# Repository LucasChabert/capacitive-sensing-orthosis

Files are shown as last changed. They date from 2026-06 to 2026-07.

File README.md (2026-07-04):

<div align="center">

# 🦾 Capteurs capacitifs imprimés en 3D pour orthèses d'exosquelette

### Capteurs de pression et de position par mesure capacitive en impression 3D multi-matériaux







*Stage de recherche L1 MPCI · Inria / IRISA, équipe Rainbow (Rennes) · Juin–Juillet 2026*

**🇫🇷 Français** · [🇬🇧 English](README.en.md)

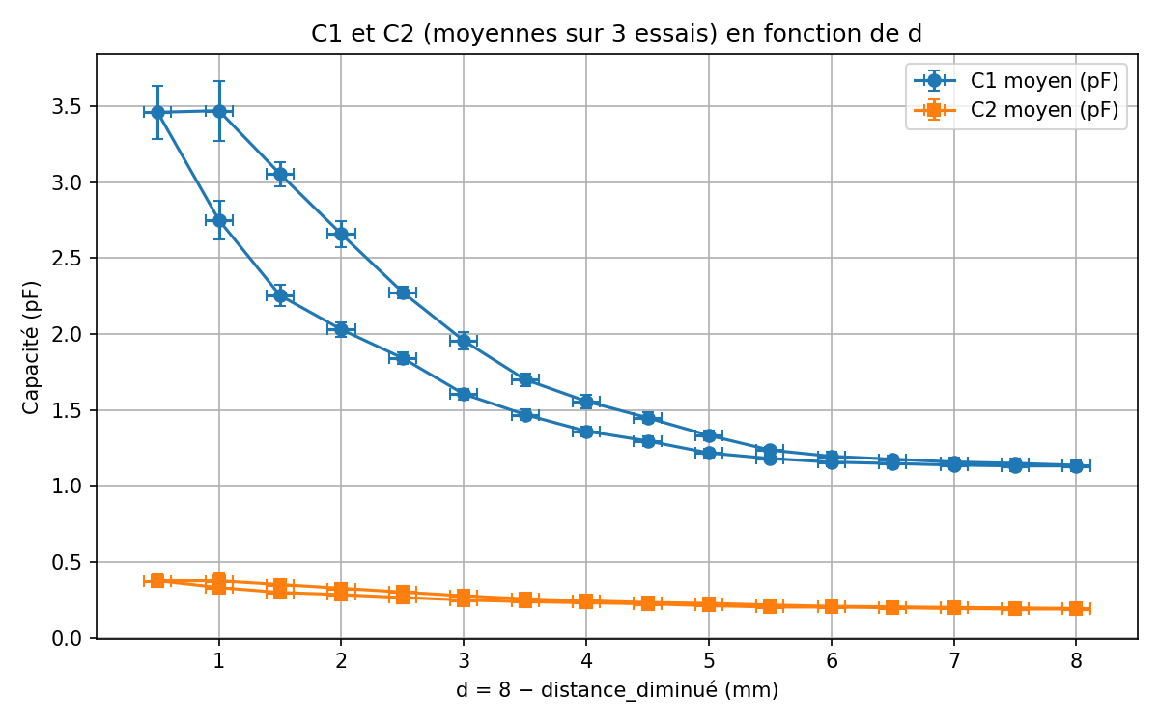
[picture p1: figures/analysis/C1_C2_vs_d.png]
Hystérésis des capacités C1 et C2 en fonction de l'écartement d


*Le résultat central du stage : pour un même écartement d, la capacité mesurée diffère
selon que la mousse diélectrique est en compression ou en relâchement — une hystérésis
interprétée comme une permittivité dépendante de l'histoire de la déformation.*

</div>

---

## 🎯 Contexte

Les exosquelettes d'assistance du membre supérieur estiment l'intention de mouvement
de l'utilisateur via des **capteurs de force 3 axes** — précis, mais lourds, encombrants
et coûteux. Ce stage explore une alternative : **intégrer des capteurs capacitifs
directement dans les orthèses** (les interfaces physiques humain–machine), fabriqués
en une seule étape par **impression 3D multi-matériaux** — matériau conducteur
(EEL 90A) pour les électrodes, élastomère souple (Filaflex 70A) pour les zones
déformables, TPU 95A pour la structure.

> 🔬 **Question** — Peut-on mesurer une pression (et sa position) avec des cellules
> capacitives imprimées, de façon suffisamment fiable pour instrumenter une orthèse ?

Le travail s'appuie sur les travaux de l'équipe Rainbow sur l'exosquelette du membre
supérieur et sur les capteurs capacitifs imprimés [1–4].

## ⚙️ Principe de mesure

Un condensateur plan suit `C = εS/d`. Pour s'affranchir de `ε` et `S`, mal connus,
on mesure **deux cellules en différentiel** séparées d'un décalage connu `Δd` :

```
d = Δd / (C1/C2 − 1)
```

Quand les électrodes sont superposées (V3), les permittivités diffèrent et le modèle
est étendu avec `α = ε1/ε2`, estimé par une calibration au repos. La chaîne de mesure :
puce **FDC1004** (mesure capacitive, blindage actif SHLD) → **M5Stack Core (ESP32)**
programmé en C++ via PlatformIO → visualisation Teleplot (résolution ±0,001 pF).

## 🔁 Démarche itérative

| Version | Conception | Enseignement |
|---|---|---|
| **V1** — cellules côte à côte | preuve de concept, mousse gyroïde | trop sensible à la position du doigt |
| **V2** — blindage | shield masse + blindage actif SHLD | perturbations environnementales fortement réduites |
| **V3** — électrodes superposées | même déformation pour les 2 cellules | nécessite le modèle à deux permittivités (α) |
| **V4** — capteur de position | électrodes triangulaires complémentaires | position via `x = L·C1/(C1+C2)`, ratio borné → calibration affine |
| **V5** — pilier / support soluble | variantes mécaniques | ouverture |

## 📊 Résultats clés

- **Hystérésis du diélectrique** mise en évidence et interprétée : la permittivité
  effective de la mousse est une **variable d'état** `ε(H)` dépendant de l'histoire de
  compression — le modèle géométrique bijectif `C = εS/d` ne suffit plus.
- **Identification de modèle** par moindres carrés (`scipy.optimize.least_squares`) :
  la forme `C(d) = A/(d+B) + C_b` ajuste les mesures, chaque paramètre ayant une
  interprétation physique (offset de contact, capacité de bord, εS).
- La grandeur `1/C2 − 1/C1`, prédite constante, est en réalité **linéaire en d
  (R² ≈ 0,95)** et moins hystérétique : c'est la compression du support « rigide » qui
  porte le signal → piste d'un **capteur à diélectrique solide**.
- **Capteur à cellule unique** : une seule courbe `C(d)` ajuste charge et décharge
  (R² = 0,91), l'hystérésis restant sous l'incertitude de mesure.
- **Capteur de position** : ratio expérimental borné dans [0,4 ; 0,6] au lieu de [0, 1],
  expliqué par un modèle à capacités parasites, corrigé par calibration affine.

## 📁 Structure du dépôt

```
├── docs/report.pdf        ← rapport de stage complet
├── firmware/              ← code embarqué ESP32 (PlatformIO)
│   ├── src/               ← main.cpp + driver FDC1004 (ProtoCentral, MIT)
│   └── variants/          ← versions pression simple / position / calibration affine
├── analysis/              ← scripts Python : fits moindres carrés, hystérésis,
│                            reconstruction de d, incertitudes
├── data/                  ← mesures du banc de test (CSV/XLSX) + acquisitions Teleplot
├── cad/                   ← modèles Fusion 360 + STL/3MF des 5 versions de prototypes
└── figures/               ← rendus CAO et figures de résultats (régénérables)
```

## 🚀 Prise en main

**Analyse (Python)** :
```bash
pip install -r requirements.txt
cd analysis
python ajustement_C1_modeles_bord_sans_offset_en_d.py   # fits C1 avec/sans effets de bord
python mesure_capacites_inverse_et_rapport.py           # linéarité de 1/C2 − 1/C1
python Retrouver_d.py                                   # reconstruction de d
```
Les figures sont écrites dans `figures/analysis/`.

**Firmware (ESP32 / M5Stack)** : ouvrir `firmware/` avec [PlatformIO](https://platformio.org/)
(`pio run -t upload`). Voir `firmware/variants/README.md` pour les autres versions.

## 👤 Auteur

**Lucas Chabert** — L1 MPCI, Aix-Marseille Université.
Stage encadré par **Maxime Manzano**, Inria/IRISA, équipe Rainbow (Rennes).

## 📚 Références

1. Aguilar-Segovia, J. E. (2026). *Additive Manufacturing of Deformable Sensing Devices for Human–Machine Interaction…* Thèse, INSA Rennes. [HAL](https://theses.hal.science/tel-05587063v1)
2. Aguilar-Segovia et al. (2024). *Multi-material torque sensor embedding one-shot 3D-printed deformable capacitive structures.* IEEE Sensors Letters 8(9). [HAL](https://hal.science/hal-04699911v1)
3. Manzano et al. (2025). *Enhancing the Usability of Upper-Limb Assistive Robots with a Variable Admittance Controller.* IFRATH 2025. [HAL](https://hal.science/hal-05356901)
4. Manzano et al. (2024). *Force-Triggered Control Design for User Intent-Driven Assistive Upper-Limb Robots.* IEEE/RSJ IROS 2024. [HAL](https://hal.science/hal-04774539v1)

---

<div align="center">

**📄 [Rapport complet (PDF)](docs/report.pdf)** 

</div>

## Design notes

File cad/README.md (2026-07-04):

# Modèles CAO (Fusion 360)

Prototypes conçus itérativement — sources `.f3d`, exports `.stl` et projets
slicer `.3mf` (PrusaSlicer, profils multi-matériaux EEL 90A / Filaflex 70A /
TPU 95A). Les `.gcode` sont exclus du dépôt (régénérables depuis les `.3mf`).

| Dossier | Version | Rapport |
|---|---|---|
| `v1_cellules_cote_a_cote/` | V1 — deux cellules côte à côte (preuve de concept) | §3.2 |
| `v2_blindage/` | V2 — introduction du blindage électrostatique | §3.4.1 |
| `v3_superpose_blinde/` | V3 — électrodes superposées + shield | §3.3 |
| `v4_position/` | V4 — capteur de position à électrodes triangulaires | §4 |
| `v5_test_pilier/` | V5 — essai avec pilier / support soluble (PVA) | ouverture |

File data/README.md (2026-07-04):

# Données expérimentales

- `Book1.csv` / `Book1.xlsx` / `Book2.xlsx` — mesures du banc de test (étau) :
  capacités C1, C2 en fonction de l'écartement d, branches charge/décharge.
  Utilisées par les scripts de `analysis/`.
- `teleplot_*.csv` — acquisitions brutes (M5Stack → Teleplot).
- `Data2.csv` — mesures du prototype V1.2 empilé.

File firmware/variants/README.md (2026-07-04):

# Variantes de firmware

Le firmware compilé par PlatformIO est `../src/main.cpp` (capteur de pression,
mesure différentielle C1/C2). Ce dossier archive les autres versions
développées pendant le stage — pour en utiliser une, remplacer le contenu de
`src/main.cpp` :

| Fichier | Rôle |
|---|---|
| `main_simple.cpp` | Lecture brute d'une seule capacité (prise en main FDC1004) |
| `main_v2.cpp` | Variante de la mesure différentielle |
| `main_DL.cpp` | Variante avec distinction charge/décharge |
| `position.cpp` | Capteur de position (électrodes triangulaires, ratio C1/(C1+C2)) |
| `position_affine.cpp` | Capteur de position avec calibration affine x = aR + b |

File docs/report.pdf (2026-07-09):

Stage de recherche — L1 MPCI

# Capteurs de pression et de position

# par mesure capacitive en impression 3D

# multi-matériaux

Application à l’instrumentation d’orthèses pour exosquelette d’assistance du membre supérieur

Inria/IRISA — équipe Rainbow

Lucas Chabert

Encadré par Maxime Manzano

du 01/06/2026 au 01/07/2026, année universitaire 2025–2026

## Table des matières

1 Introduction | 1
2 Principe de fonctionnement | 2
3 Développement d’un capteur de pression | 4
4 Vers une mesure de la position du point de pression | 13
5 Conclusion et ouverture | 15
Remerciements | 15
A Capacité équivalente en série | 16
B Expression de C2 en fonction de d | 16
C Méthode des moindres carrés | 17
D Coefficient de détermination | 17
E Bornes du ratio du capteur de position | 18

Capteurs capacitifs imprimés en 3D | Inria/IRISA — Rainbow

## 1 Introduction

La perte de mobilité du membre supérieur, qu’elle soit d’origine neurologique, musculaire ou traumatique, affecte profondément l’autonomie des personnes concernées dans les gestes de la vie quotidienne. Pour tenter de la restaurer, la recherche en robotique d’assistance s’est tournée vers le développement d’exosquelettes. Un exosquelette est une structure mécanique articulée, portée par l’utilisateur et alignée sur les segments de son corps, dont les moteurs travaillent en parallèle des muscles afin d’assister le mouvement. Une orthèse est un dispositif d’interface, solidaire d’un segment du membre, assurant la liaison physique entre l’utilisateur et la structure de l’exosquelette : c’est à travers les orthèses que sont transmis les efforts entre l’humain et la machine.

Pour qu’un exosquelette assiste un mouvement de manière fluide et naturelle, encore faut-il qu’il puisse anticiper ce que l’utilisateur souhaite faire : c’est le rôle de la détection d’intention. Cette anticipation doit cependant rester mesurée, car une surinterprétation du mouvement restreindrait la liberté de l’utilisateur.

Un prototype d’exosquelette du membre supérieur a été développé au laboratoire dans ce contexte. Ce dispositif se présente comme une chaîne de corps rigides articulés, actionnée par trois moteurs, et dotée de capteurs de force à trois axes au niveau de ses fixations avec l’utilisateur. Ces capteurs mesurent les efforts d’interaction et permettent d’estimer les intentions de mouvement, sur lesquelles s’appuie le pilotage de l’exosquelette [1, 2].

Toutefois, ces capteurs de force présentent un inconvénient majeur : relativement lourds, encom-brants et coûteux, ils limitent l’accessibilité de la solution. Il est donc pertinent de rechercher des méthodes alternatives, plus légères et moins onéreuses, pour estimer l’intention de mouvement.

La piste explorée dans ce stage consiste à intégrer des capteurs de pression directement au sein des orthèses, afin de mesurer les déformations locales induites par les efforts de l’utilisateur. Outre l’estimation de l’intention de mouvement, une telle instrumentation présente un second intérêt : vérifier que les tissus mous du membre ne sont pas soumis à des pressions excessives au niveau des interfaces, susceptibles d’engendrer des douleurs ou des points de compression lors d’un port prolongé. Ces orthèses étant aujourd’hui partiellement fabriquées par impression 3D, l’idée directrice est de produire les capteurs au cours de cette même étape de fabrication, en exploitant l’impression 3D multi-matériaux. Les capteurs envisagés prennent la forme de cellules capacitives, selon une méthode développée dans des travaux antérieurs [3, 4].

Ce stage s’est déroulé au sein de l’équipe Rainbow, équipe-projet commune au centre Inria de l’université de Rennes et à l’IRISA (Institut de Recherche en Informatique et Systèmes Aléatoires), sur le campus de Beaulieu à Rennes. Il s’inscrit dans les travaux de l’équipe sur le développement de l’exosquelette d’assistance du membre supérieur mentionné précédemment. L’équipe Rainbow travaille sur la robotique commandée par capteurs et l’interaction homme-robot, notamment les dispositifs d’assistance aux personnes en perte d’autonomie.

Objectif et contributions. L’objectif de ce travail est de démontrer la faisabilité de capteurs capacitifs imprimés en 3D pour l’instrumentation d’orthèses, et d’en caractériser les limites. Les objectifs sont :

1. la conception et la fabrication de capteurs de pression capacitifs, dans une démarche itérative de prototypage ;
2. une ouverture vers la conception d’un capteur de position.

Plan. Le présent rapport suit cette démarche. On rappelle d’abord le principe de la mesure capacitive et le procédé de fabrication par impression 3D multi-matériaux (section 2). On détaille ensuite la conception itérative du capteur de pression et son évaluation expérimentale (section 3), puis le capteur de position (section 4), avant de conclure sur les limites et les perspectives de ce travail (section 5).

## 2 Principe de fonctionnement

D ans cette partie, on va présenter les connaissances pré-existantes au projet : le principe de la mesure capacitive, puis la méthode de fabrication d’un capteur, et enfin la chaîne de mesure permettant de mesurer cette capacité électrique.

### 2.1 Théorie : capacité électrique

Définition 2.1 (Capacité électrique). La capacité électrique est définie comme l’aptitude d’un composant, généralement un condensateur, à stocker une charge électrique. Elle est mesurée en farads (F) et est déterminée par le rapport entre la charge accumulée sur les armatures du condensateur et la tension appliquée entre elles.

Définition 2.2 (Capteur capacitif). Un capteur capacitif mesure la variation de capacité électrique d’une structure déformable : lorsqu’un effort modifie la géométrie du capteur (par exemple la distance entre deux armatures), la capacité varie de manière mesurable, fournissant une image de l’effort appliqué.

La grandeur physique exploitée est la capacité d’un condensateur plan, de surface d’armature S, d’écartement d et de permittivité diélectrique ε obtenue par la relation :

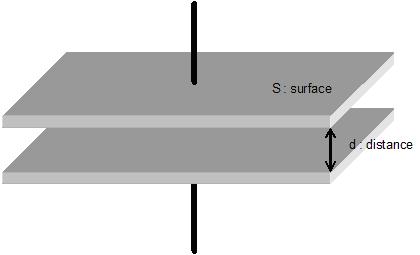
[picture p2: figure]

Figure 1. Condensateur plan et grandeurs associées : surface S du diélectrique, distance d.

C = ε

S
d
. | (1)

La relation (1) montre que toute variation de l’écartement d se traduit par une variation de C. C’est ce lien qui sera exploité : un effort qui comprime la structure rapproche les armatures, donc augmente C. On pourra par la suite estimer la force appliquée à partir de la distance grâce à la physique des matériaux. Dans ce stage, on s’intéresse surtout à estimer la valeur de d.

### 2.2 Fabrication par impression 3D multi-matériaux

Le développement d’une pièce commence par sa conception sous forme d’un modèle numérique en trois dimensions, réalisé à l’aide d’un logiciel de CAO.
Définition 2.3 (Conception assistée par ordinateur (CAO)). La CAO désigne l’ensemble des logiciels permettant de concevoir, modéliser et représenter numériquement un objet en trois dimensions. Elle fournit une description géométrique précise de la pièce, qui peut ensuite être simulée, modifiée, puis exportée vers les étapes de fabrication : en particulier vers le slicer dans le cas de l’impression 3D. Le logiciel utilisé ici est Fusion 360.

Vient ensuite la fabrication, qui repose sur l’impression 3D par dépôt de fil fondu : un procédé de fabrication durant lequel un objet est construit couche par couche par extrusion d’un matériau plastique fondu.
Définition 2.4 (Filament et matériau). Le filament est la matière première de l’impression par dépôt de fil fondu : un fil de plastique conditionné en bobine, porté à sa température de fusion par une tête chauffante avant d’être déposé. Le matériau désigne la nature de ce plastique. Chaque matériau possède des propriétés mécaniques, thermiques et électriques propres : le PLA (rigide, peu coûteux), l’ABS (résistant à la chaleur), ou le TPU, un élastomère flexible adapté aux structures déformables.

L’impression d’une orthèse instrumentée fait intervenir plusieurs matériaux aux rôles distincts : un matériau rigide pour la structure portante, un matériau souple pour les zones déformables des capteurs, et un matériau conducteur pour les électrodes. On parle alors d’impression 3D multi-matériaux.

Pour catégoriser un matériau, on utilise la dureté Shore, qui mesure sa résistance à la pénétration sur une échelle de 0 à 100 : plus la valeur est faible, plus le matériau est souple. Pour situer, un TPU courant se situe autour de Shore 95A.
Définition 2.5 (Slicer). Un slicer est un logiciel qui découpe un modèle 3D en couches horizontales successives, puis génère le parcours de la tête d’impression couche par couche. Il produit un fichier de commande (G-code) précisant déplacements, températures et débits.

Choix des matériaux. La fabrication des capteurs met en jeu trois matériaux complémentaires : un matériau conducteur, l’EEL 90A, pour les électrodes ; un matériau souple, le Filaflex 70A, pour les zones déformables ; et un matériau rigide, le TPU 95A, pour la structure portante. Ce choix reprend celui de travaux antérieurs menés au laboratoire [3, 4], ainsi que la contrainte des disponibilités.

### 2.3 Chaîne de mesure

L’acquisition des mesures capacitives repose sur une chaîne matérielle et logicielle articulée autour de trois composants principaux (figure 2) : la puce de mesure capacitive, le microcontrôleur qui la pilote, et l’ordinateur qui reçoit et visualise les données.

La FDC 1004 est un convertisseur capacité-vers-numérique, à une fréquence d’échantillonnage de 25 kHz maximum, doté d’entrées de blindage actif SHLD (voir section 3.1.3). La puce permet de mesurer jusqu’à 4 capacités électriques . La mesure de la capacité sera prise avec une fréquence de 21 Hz.

La M5Stack Core, module autour du microcontrôleur ESP 32, assure l’interface entre la FDC 1004 et l’ordinateur. Elle est programmée en C++ via l’extension PlatformIO, qui permet de développer pour les microcontrôleurs de type Arduino ou ESP 32.

Enfin, sur l’ordinateur, l’extension Teleplot de VSCode reçoit les valeurs transmises par la M5Stack via une liaison USB série et les trace en temps réel, ce qui permet à la fois le suivi visuel et l’export des données pour analyse.

Capteur

(2 cellules)

FDC 1004

mesure de C

M5Stack Core

ESP 32, C++

Ordinateur

Teleplot

C1, C2 | I
2C | USB

Figure 2. Chaîne de mesure : la FDC 1004 mesure les capacités du capteur et transmet les valeurs numériques à la M5Stack Core par bus I

2C ; celle-ci les envoie sur l’ordinateur par liaison USB série, où elles sont visualisées et enregistrées via Teleplot.

## 3 Développement d’un capteur de pression

### 3.1 Développement itératif

Trois prototypes ont été conçus et fabriqués au cours du stage, chacun répondant à une limite identifiée du précédent. On présente ci-dessous leur principe, leur construction et les enseignements qui en ont été tirés.

### 3.1.1 Premier prototype : mesure différentielle à deux cellules

appui de la main
électrode haute | électrode haute
Cellule 1 | Cellule 2

électrode basse

électrode basse

cale solide

d
d + ∆d

∆d

S | S

Figure 3. Premier prototype (V1) : deux cellules côte à côte, partageant le même diélectrique en mousse (ε) et la même surface S. Les électrodes hautes des deux cellules sont reliées entre elles

Principe de la mesure différentielle. Mesurer d à partir d’une seule capacité via (1) suppose de connaître ε et S avec précision, ce qui est difficile en pratique. On adopte donc un montage à deux cellules de géométrie identique au repos, séparées par un décalage fixe et connu ∆d (figure 3). La première cellule se comporte comme un condensateur plan d’écartement d :

C1 = ε

S
d
, | (2)

C2 = ε

S
d + ∆d
, | (3)

où d désigne l’écartement de la première cellule, grandeur à estimer. En éliminant le produit εS commun à (2) et (3), d s’exprime à partir du seul rapport C1/C2 et du décalage connu ∆d. On obtient en effet C1d = C2(d + ∆d), d’où :

d =

C2 ∆d
C1 − C2

=

∆d
C1
C2

− 1

. | (4)

L’intérêt du montage est que cette dépendance différentielle enlève les incertitudes liées à la mesure de ε et S. Néanmoins, une incertitude sur ∆d persiste, notamment durant l’impression de la pièce.

Remarque 3.1 (Hypothèse du modèle). Les relations (2)–(3) ne constituent qu’un modèle de base, dérivé de l’hypothèse idéale du condensateur plan à électrodes infinies. En pratique, quatre écarts l’invalident partiellement :
— Effets de bord : les bords des électrodes finies ajoutent une capacité parasite ignorée ici. — Permittivité non constante : ε dépend de l’état de contrainte (proportion d’air, densité, géométrie).
— Déformation non uniforme : la surface équivalente n’est identique entre les deux cellules que si l’appui est centré.
— Absence d’interaction : C1 et C2 sont supposées découplées, sans garantie qu’aucun offset (décalage) n’en découle.

Fabrication. Le premier capteur constitue une preuve de concept : il ne vise pas à produire un capteur abouti, mais à valider expérimentalement le principe de mesure avant de l’affiner. La pièce a d’abord été modélisée avec un support solide destiné à maintenir constant le décalage ∆d entre les deux cellules. Les électrodes et la mousse ont ensuite été ajoutées : la mousse assure un rappel élastique, permettant une déformation sous l’effort puis le retour du capteur à son état initial une fois la sollicitation relâchée. Elle est obtenue grâce à un matériau non rigide et un motif de remplissage « gyroïde », qui se comporte comme un ressort.

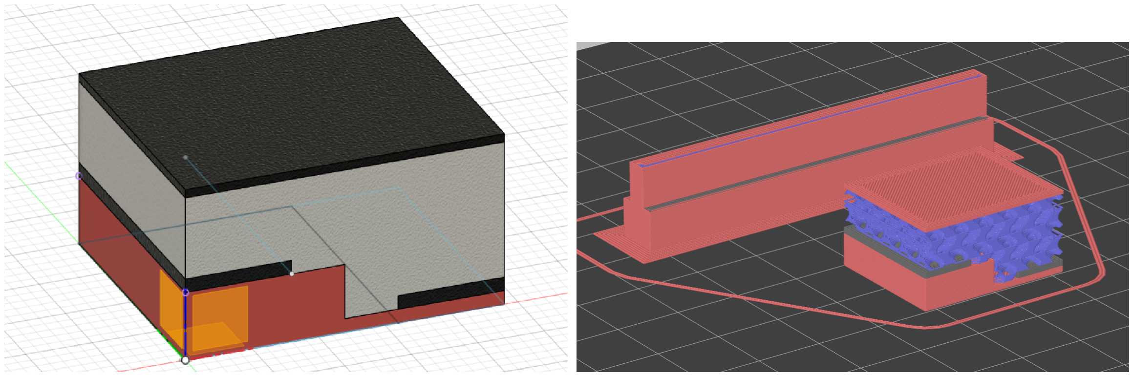
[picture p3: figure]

Figure 4. Différentes étapes de la pièce : perspective cavalière en CAO (gauche) ; vue dans le slicer après découpage (droite). La pièce allongée visible à côté du capteur est la tour de nettoyage, utilisée pour purger les résidus de filament lors des changements de matériau.

Le principe de mesure est le suivant : lorsque la main de l’utilisateur appuie sur le plafond du capteur, elle exerce une contrainte qui rapproche les armatures et modifie la capacité. La variation de capacité fournit alors une image de l’effort appliqué. La main permet également de fermer le circuit électrique en reliant les deux électrodes hautes.

Figure 5. Photo du capteur 1 après impression. La partie grise est la mousse, les deux parties noires sont les électrodes et le reste est le support.

Limites observées. Les résultats montrent que la valeur de d estimée via (4) est très sensible à la position du doigt et peu à la pression. Plusieurs causes principales sont identifiées :
— Dépendance au point d’appui : si le doigt appuie d’un côté, la déformation n’est pas uniforme et les deux cellules ne se compriment pas de la même manière, ce qui biaise l’estimation.
— Effets de bord : des essais complémentaires montrent qu’une électrode centrale ponctuelle concentre la mesure au centre et réduit cet effet.
— Couplages parasites : la mesure varie selon qu’une main s’approche ou touche la table, ce qui indique que l’appareil de mesure ne mesure pas uniquement la capacité entre le doigt et la plaque conductrice.

### 3.1.2 Second prototype : électrodes superposées

Le premier capteur a mis en évidence que les deux cellules ne subissent pas la même déformation lorsque l’appui n’est pas centré, ce qui invalide l’hypothèse de déformation uniforme. Pour réduire cet effet, le second capteur superpose les deux électrodes sur un même axe vertical, de sorte qu’elles subissent la même déformation géométrique par rapport à l’électrode supérieure.

Armature supérieure (EEL)

Mousse (air + Filaflex), ε1

Électrode du milieu
Support solide (TPU), ε2
Armature inférieure (EEL)

d

∆d

S (surface en regard)

C1 = ε1S/d

C12 = ε2S/∆d

sup.

milieu

inf.

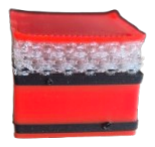
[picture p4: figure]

Figure 6. Second capteur à électrodes superposées (gauche). Photo du second capteur à électrodes superposées après impression. (droite).

De plus, la grande surface du capteur impose une déformation orthogonale à celle-ci par contrainte mécanique, ce qui répond à la problématique de l’angle d’appui qui faussait la mesure. Néanmoins, cette géométrie introduit une différence de nature diélectrique entre les deux cellules : l’électrode inférieure a sur son chemin un matériau solide non conducteur supplémentaire (le support rigide séparant les deux cellules) et également l’autre électrode, dont les permittivités relatives sont supérieures à celle de l’air. Néanmoins, on néglige la permittivité de l’électrode supérieure dans une première modélisation. La permittivité effective ε2 du condensateur inférieur diffère donc de ε1, et l’hypothèse ε1 = ε2 du modèle initial n’est plus valide. Le modèle doit être amélioré.

On modélise la première capacité par :

C1 = ε1

S
d
. | (5)

La deuxième cellule correspond à deux condensateurs en série (d’après la démonstration en annexe A) : 1
C2

=

1
C1

+

1
C12

, où C12 est la capacité entre l’électrode du bas et celle du milieu. On obtient :
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
. | (6)

Le rapport des deux capacités donne : C1
C2

=

ε1
ε2

·

∆d
d
+ 1. | (7)

Le rapport ε1/ε2 est inconnu, mais on l’élimine en introduisant un état de référence mesuré en l’absence de déformation (d = d0). Avec C1,0, C2,0 mesurées au repos et d0 connu (mesuré mécaniquement sur la pièce imprimée), on isole :

ε1
ε2

=

C1,0

C2,0

− 1

!
·

d0
∆d
. | (8)

En posant α = ε1/ε2 et en substituant dans (7), on isole d :

d = α ·

∆d
C1
C2

− 1

. | (9)

Ainsi, d est entièrement déterminé par les mesures courantes C1, C2 et les constantes de calibration C1,0, C2,0, d0, ∆d, sans qu’il soit nécessaire de connaître ε1 ni ε2 séparément.

Critère de conception : sensibilité et couplage. On cherche à maximiser l’amplitude du signal pour une intention donnée. Les paramètres de conception disponibles sont ∆d, d0 et α. À partir de (7) :

∂(C1/C2)
∂d

=

α ∆d
d

2

. | (10)

Cette quantité est décroissante en d ; son minimum sur [0, d0] est atteint en d0. Maximiser ce minimum garantit une bonne sensibilité sur tout l’intervalle, ce qui pousse à maximiser ∆d et α, et à minimiser d0. Toutefois, si ∆d ou α sont trop grands, le champ électrique de C2 se couple avec l’environnement (air, mobilier, câbles) plutôt qu’avec l’électrode supérieure. En repartant de (6), on exprime C2 en fonction de d (détail en annexe B) :

C2(d) = Sε1
α ∆d + d

=⇒

∂C2
∂d (d0)

=

Sε1
(α ∆d + d0)

2

. | (11)

Il faut donc essayer de minimiser α ∆d. Ces deux critères sont antagonistes vis-à-vis de α ∆d : la conception relève donc d’un compromis. C’est ce constat, ainsi que la présence de couplages parasites déjà observés sur la V1, qui motivent le troisième prototype.

### 3.1.3 Troisième prototype : blindage électrostatique

Le second prototype confirme la sensibilité du signal utile aux contributions parasites de l’environnement (main s’approchant, contact avec la table, câbles). Pour y remédier, on emploie un blindage électrostatique (shield) : un conducteur entourant les câbles et l’électrode pour isoler le capteur des perturbations.

Blindage actif piloté. Le conducteur est maintenu au même potentiel que l’électrode de mesure (figure 7a). Faute de différence de potentiel entre les deux, aucune capacité n’est mesurée dans la direction blindée, et les perturbations se couplent au blindage plutôt qu’à l’électrode. C’est le principe des sorties SHLD de la FDC 1004, utilisées ici pour piloter le blindage entourant l’électrode.

doigt

électrode

environnement

environnement

blindage

SHLD
Vblindage = Vâme

champ utile (signal mesuré)

champ parasite (perturbation)

(a) Principe du blindage actif : ∆V = 0 entre blindage et âme, aucune capacité mesurée dans la direction blindée.

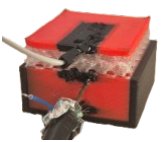
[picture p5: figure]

(b) Troisième prototype : blindage à la masse (câbles RJ45), blindage actif SHLD, plaques réduites.

Figure 7. Blindage actif piloté par les sorties SHLD de la FDC 1004 et photographie du prototype imprimé correspondant. Les perturbations extérieures se couplent au blindage sans influencer la mesure.

La protection repose donc sur le pilotage actif par la sortie SHLD de la FDC 1004.

Réduction des plaques. En parallèle du blindage, la surface des électrodes a été réduite afin de limiter le couplage résiduel avec le blindage actif environnant, qui, à surface d’électrode égale, aurait consommé une part croissante du champ utile.

### 3.2 Évaluation expérimentale

### 3.2.1 Protocole expérimental

Un banc de test a été mis en place pour relier la capacité mesurée à une distance connue. Le capteur est placé dans un étau dont l’axe possède un pas connu : à partir de l’angle de rotation appliqué à l’axe, on remonte directement à la variation d’écartement d. Concrètement, on impose d = 8 − 4 tour (en mm) pour une expérience nominale sur toute la course de compression.

Le protocole consiste à parcourir l’intervalle [dmin, dmax] par paliers successifs, dans le sens de la compression (charge) puis dans le sens du relâchement (décharge). À chaque palier, on attend quelques secondes que la mesure se stabilise, puis on relève C1 et C2 à travers Teleplot. Chaque point rapporté correspond à la moyenne de n = 3 mesures, prises dans les mêmes conditions.

Incertitude de mesure. On estime environ 10◦ d’incertitude sur les angles, soit ±10◦ ∼
1
9 mm
sur le déplacement. On suppose le bruit de mesure de la capacité centré autour de la vraie valeur. Avec des valeurs plus précises, on pourrait reconstruire la distribution et en déduire une

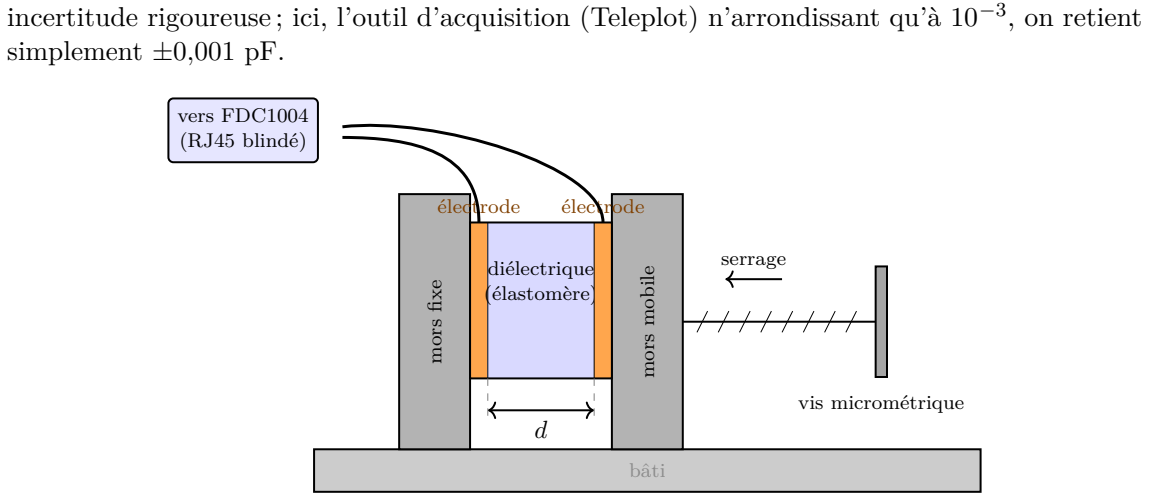
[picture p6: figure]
, on retient; simplement ±0,001 pF.; bâti; mors fixe; mors mobile; vis micrométrique; serrage diélectrique; (élastomère); électrode; vers FDC1004 (RJ45 blindé)

incertitude rigoureuse ; ici, l’outil d’acquisition (Teleplot) n’arrondissant qu’à 10⁻³

Figure 8. Banc de test mécanique : le capteur capacitif (deux électrodes séparées par le diélectrique élastomère imprimé) est placé entre les mors d’un étau. La vis micrométrique impose l’écartement d entre les électrodes ; les deux armatures sont reliées à la carte FDC1004 par le câble RJ45 blindé.

### 3.2.2 Résultats

Le modèle géométrique n’est pas suivi. Une fois la reconstruction d = α ∆d/(C1/C2 − 1) appliquée aux mesures, on constate que la distance reconstruite varie dans le bon sens avec la compression imposée, mais que les valeurs ne sont pas cohérentes avec la géométrie réelle : pour une compression imposée de ∼ 2 mm, on reconstruit ∼ 4 mm. L’écart, d’un facteur voisin de deux, pourrait provenir de la sensibilité de la constante α à l’unique point de calibration au repos. Comme α est estimé via (8) à partir du seul couple (C1,0, C2,0) mesuré en d0, toute erreur sur ce point se propage directement en facteur multiplicatif sur d reconstruit.

Deux écarts au modèle sont ensuite systématiquement observés.

Observation 1 : hystérésis. La variation de capacité n’est pas la même selon le sens du trajet (compression ou relâchement) (figure 9). Ce phénomène s’appelle l’hystérésis : pour un même écartement d, la capacité mesurée diffère selon que la mousse est en cours de compression (charge) ou de relâchement (décharge). Ce comportement est incompatible avec le modèle géométrique pur C = εS/d, qui est bijectif : à un écartement d ne peut correspondre qu’une seule valeur de capacité. Il faut donc identifier l’origine physique de cette boucle.
Définition 3.2 (Hystérésis). Une hystérésis est une dissymétrie du comportement d’un système selon qu’une cause extérieure augmente ou diminue. Le système garde la mémoire de son histoire.

Origine retenue : la permittivité comme variable d’état. L’hystérésis provient de la mousse diélectrique elle-même. Comme indiqué en section 2, le diélectrique est composé d’air et de matériau imprimé, et sa permittivité effective ε dépend de l’état de contrainte : la compression modifie la proportion d’air, la densité du matériau et la géométrie du diélectrique. Or l’état micro-structural atteint pour un écartement d donné n’est pas le même selon l’histoire de compression : à d fixé, la mousse est plus tassée lors de la décharge que lors de la charge. La permittivité effective dépend donc non seulement de l’écartement courant, mais aussi du chemin parcouru pour l’atteindre.

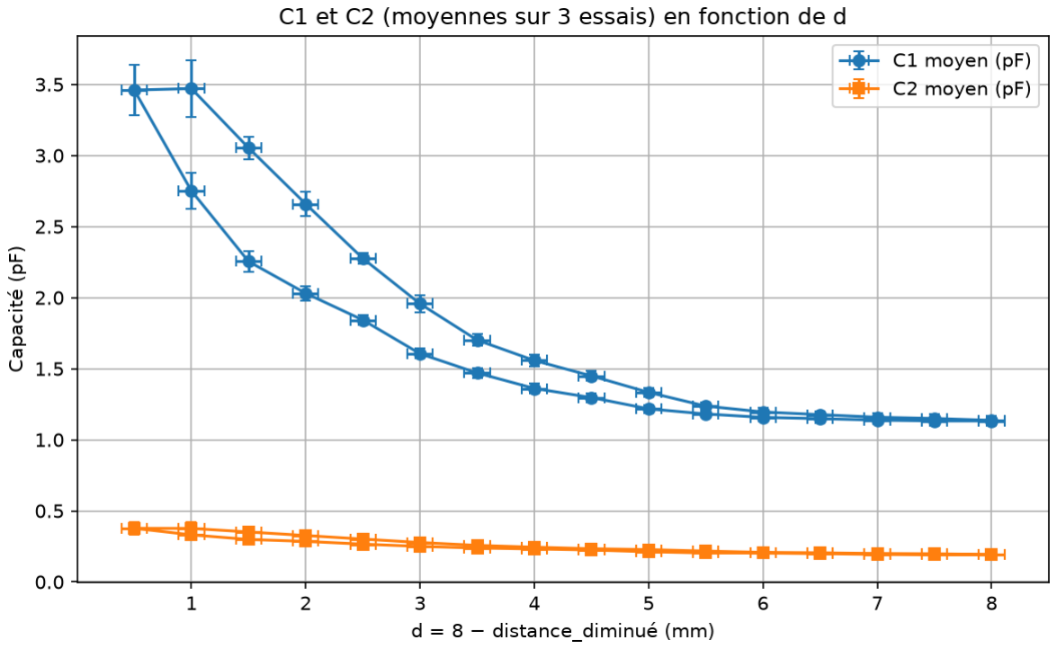
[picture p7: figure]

Figure 9. Mise en évidence du phénomène d’hystérésis : pour un même écartement, la capacité diffère selon que la mousse est en cours de compression ou de relâchement. L’échelle de valeurs est cohérente car, d’après (6), 1/C2 > 1/C1. C1 et C2 moyens correspondent aux valeurs moyennes pour 3 mesures en fonction de d.

Définition 3.3 (Permittivité comme variable d’état). La loi C = εS/d demeure exacte à chaque instant : la capacité ne dépend que de la géométrie et de la permittivité courantes. Toutefois, pour un diélectrique à comportement hystérétique, la permittivité effective ε n’est pas une constante du matériau mais une variable d’état : sa valeur dépend de l’histoire de la déformation subie. On écrit alors
C =

ε(H) S
d

,

où H désigne l’histoire de compression du diélectrique. La mesure de d à partir de la seule capacité courante n’est donc exacte que si ε est préalablement caractérisée en fonction de cette histoire.

Ce résultat constitue une limite au modèle de mesure, qui suppose ε constante.

Observation 2 : C1 et C2 ne tendent pas vers 0. Le modèle géométrique (1) prédit que C → 0 lorsque d → +∞. Or les mesures montrent que C1 et C2 tendent vers une valeur strictement positive lorsque l’écartement devient grand. Cette capacité résiduelle pourrait traduire la présence d’effets de bord : le champ électrique ne se limite pas au volume entre les armatures, et une part de la capacité provient des lignes de champ qui contournent les électrodes. Ces effets de bord sont d’autant plus visibles que les électrodes sont de petite taille par rapport à l’écartement, ce qui est notre cas après la réduction des plaques introduite au troisième prototype.

### 3.2.3 Estimation de la distance de déformation

Faute de modèle géométrique exact (effets de bord, permittivité variable), on adopte une approche empirique : on postule une forme fonctionnelle C = f(d ; θ) dépendant de quelques paramètres θ, puis on choisit les paramètres qui rapprochent au mieux le modèle des N couples mesurés (di

, Ci)
sur le banc de test. La méthode des moindres carrés (annexe C) permet de tester des fonctions pour retenir celle qui caractérise le mieux notre phénomène.

Forme retenue pour C1. Parmi les formes testées, celle qui ajuste le mieux les données est, avec Ach, Ad´e, B, C des réels :

C1(d) =

Ach

d + B

+ C en charge (compression),

Ad´e

d + B

+ C en décharge (relâchement).

(12)

Les paramètres B et C sont communs aux deux branches ; seul A prend une valeur distincte selon le sens de sollicitation. Chaque paramètre admet une interprétation physique :

— B est un offset sur l’écartement : on ne connaît pas précisément l’origine de la compression (l’instant où le contact s’établit), et B absorbe cette incertitude sur le zéro de d. Cette incertitude étant purement géométrique, elle ne dépend pas du sens de sollicitation : B est donc partagé entre les deux branches.
— C est une capacité de bord constante : lorsque d devient grand, le terme en 1/(d + B) tend vers 0 et C1 → C. C représente donc la capacité résiduelle due aux effets de bord, indépendante de l’écartement — ce qui rejoint directement l’observation 2 ci-dessus. Les effets de bord étant fixés par la géométrie des électrodes, C est lui aussi commun aux deux branches.
— Ach et Ad´e sont homogènes à ε1S et portent donc l’information sur la permittivité ε1. C’est le seul paramètre qui varie entre charge et décharge : l’écart entre les deux valeurs traduit l’hystérésis diélectrique du matériau, la permittivité apparente n’étant pas la même selon que l’élastomère est en cours de compression ou de relâchement.

Forme retenue pour C2. La seconde cellule étant en série avec la première (annexe A), on relie C2 à C1 par :
1
C2

=

1
C1

+

∆d
ε2 S
, | (13)

où le terme additionnel ∆d/(ε2S) rend compte de la couche solide d’épaisseur ∆d et de permittivité ε2. Cette relation confirme que C2 n’est pas indépendante : elle se déduit de C1 et du seul paramètre supplémentaire ε2, lui aussi ajusté par moindres carrés.

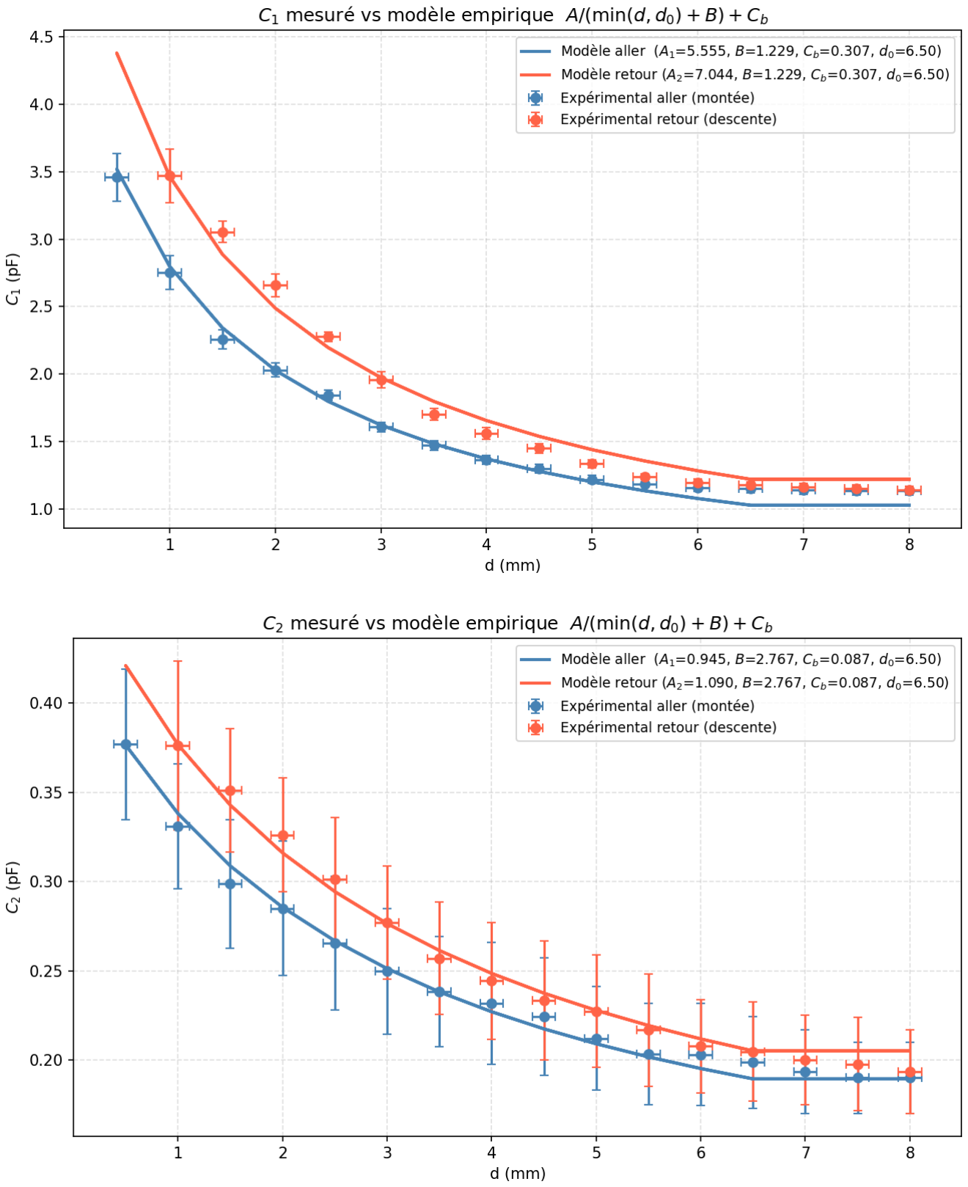
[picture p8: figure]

Figure 10. C1 et C2 en fonction de d. Le fit utilise min(d, d0) car la compression ne démarre pas à d = 8 mais au moment où la mousse s’écrase, c’est-à-dire d = 6,5.

### 3.3 Synthèse et ouverture

Pistes de résolution de l’hystérésis. L’hystérésis étant identifiée et interprétée, trois leviers complémentaires permettent d’en limiter l’effet sur la reconstruction de d :

— Caractériser la permittivité ε(H) : il existe des modèles de l’hystérésis, et l’on pourrait mener une étude des matériaux pour tenter de la modéliser. Néanmoins, cette démarche est très complexe et trop longue pour un stage de L1.
— Redessiner la géométrie du capteur : baisser la proportion de matériau par rapport à l’air pour diminuer l’hystérésis, et faire l’approximation de la linéarité.
— Corriger par calibration empirique : à défaut de modèle physique complet, on ajuste directement une fonction reliant les capacités mesurées à d (section 3.2.3), en intégrant éventuellement le sens du trajet (charge/décharge) comme variable supplémentaire pour lever l’ambiguïté de la boucle.

On essaie la deuxième méthode, car la première est trop difficile et la troisième complexifie trop la démarche. Notre objectif reste l’accessibilité.

Vers un capteur à diélectrique solide ou à air dominant. L’analyse de la grandeur 1/C2 − 1/C1 apporte un éclairage inattendu. Le modèle (13) la prédit constante (∆d/(ε2S)), or les mesures la montrent linéaire en d (R² ≈ 0,95, annexe D), bien au-delà du bruit : la couche solide n’est donc pas parfaitement indéformable, et c’est sa compression qui porte le signal. Surtout, cette grandeur est nettement plus linéaire et moins hystérétique que C1 ou C2 pris séparément, ce qui suggère que la déformation du solide est plus réversible (permittivité quasi constante).

1/C2 − 1/C1 = ∆d/(ε2S) = 1/C12 : cette grandeur isole donc la capacité C12 de la seule couche solide, entre l’électrode du milieu et l’armature inférieure, en éliminant la contribution de la mousse.

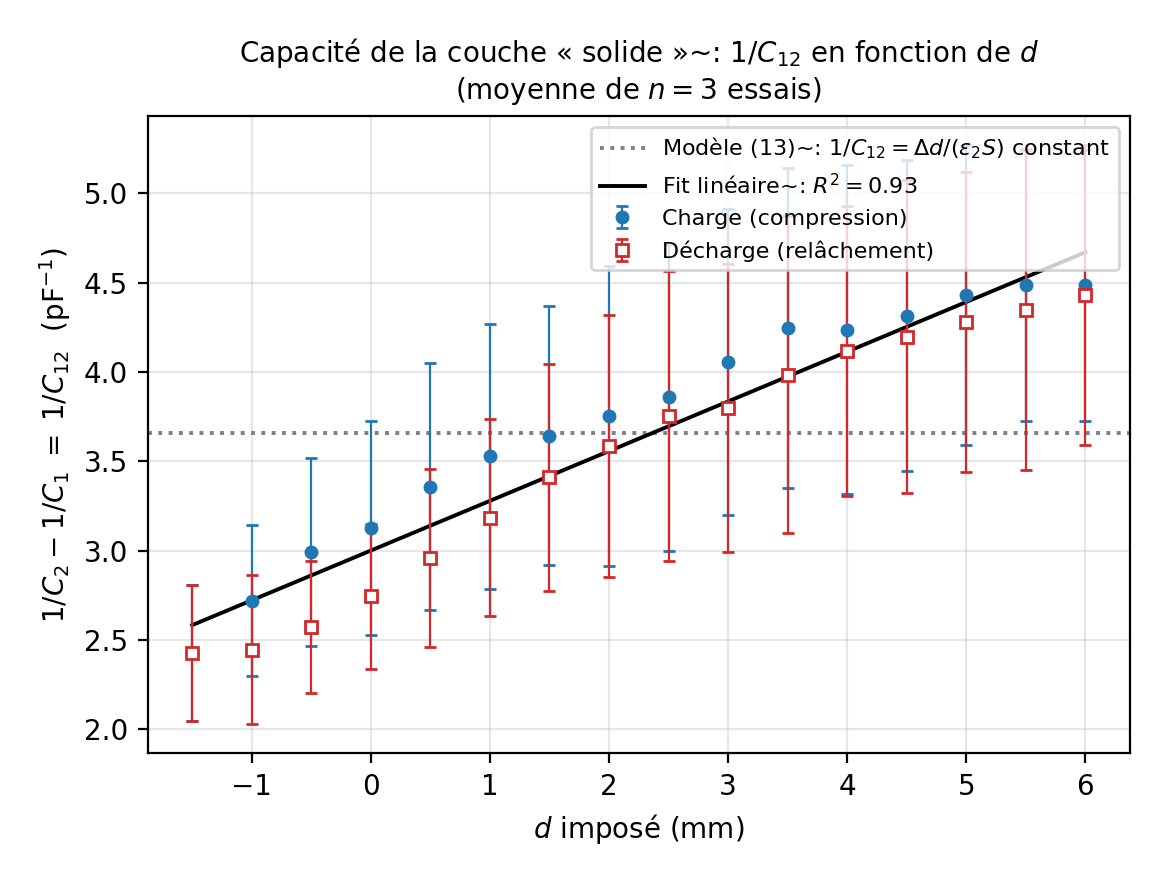
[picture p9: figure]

Figure 11. Grandeur 1/C2 − 1/C1 = 1/C12 en fonction de l’écartement imposé. Le modèle la prédit constante (pointillés gris) ; les mesures suivent une loi affine en d (R² = 0,93) : la couche solide se comprime donc elle aussi. Contrairement à C1 et C2 (figures 12–14), les branches de charge et de décharge se superposent quasiment : la déformation du solide est plus réversible que celle de la mousse.

Deux évolutions en découlent. On peut remplacer la mousse par un bloc élastomère plein mesuré par une unique cellule, échangeant une part de sensibilité contre une hystérésis fortement réduite ; le paramètre de conception central devient alors la dureté Shore, à la frontière entre déformabilité mesurable et réversibilité. À l’inverse, on peut maximiser la proportion d’air — la mousse n’assurant que le rappel élastique latéral —, ce qui supprime l’essentiel de l’hystérésis au prix d’une capacité, donc d’une sensibilité, plus faible.

Ouverture : capteur à cellule unique et diélectrique à air dominant. L’idée directrice est ici de pousser à son terme la piste « plus d’air, moins d’hystérésis » : en maximisant la proportion d’air dans le diélectrique, on cherche à rendre l’hystérésis suffisamment faible pour la négliger, et ainsi décrire le capteur par une unique courbe C(d) (sans distinguer charge et décharge). Un premier essai a été mené dans cette direction, avec une seule cellule.

Il faut souligner d’emblée les limites de cet essai. En raison de la canicule, les imprimantes 3D n’ont pas pu être utilisées sur cette période ; les capteurs ont donc été bricolés à la main plutôt qu’imprimés. Les incertitudes associées sont par conséquent très élevées, et ces mesures ne constituent pas une caractérisation valide. Elles permettent néanmoins de dégager une tendance, présentée ici à titre d’ouverture. L’acquisition des valeurs se fera avec le même banc de test que les prototypes précédents.

La distance est reconstruite à partir du nombre de tours de l’étau via d = 8−4 tour (en mm), et la capacité est ajustée par le modèle empirique C = A/(d+B) +Cb — sans le plafond min(d, d0), la compression démarrant ici dès le premier tour, et sans séparer charge et décharge, conformément à l’hypothèse d’hystérésis négligeable (figure 12).

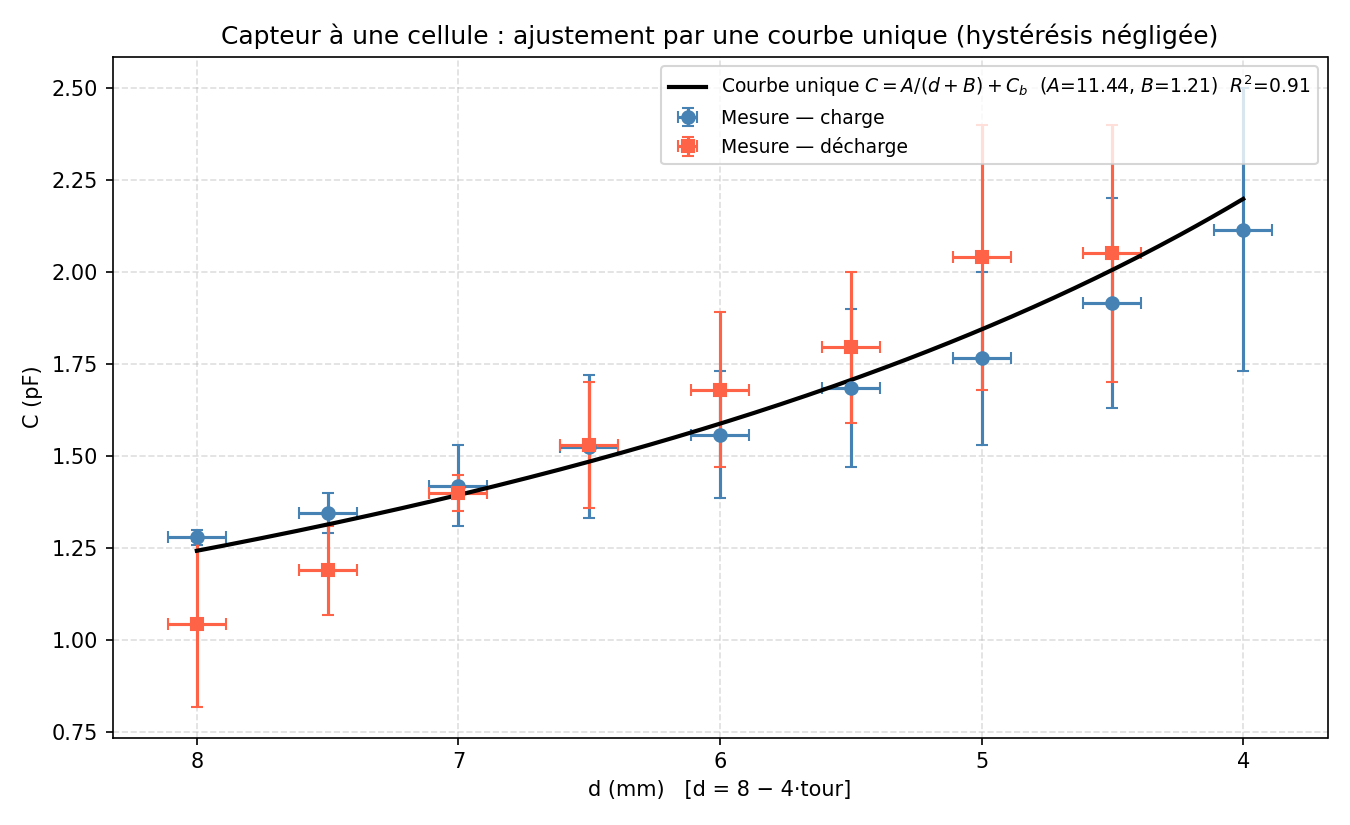
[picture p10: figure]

Figure 12. Capteur à une cellule unique : capacité mesurée (deux essais moyennés, branches de charge et de décharge) en fonction de d = 8 − 4 tour. Le modèle a été traduit par une unique courbe.

Les barres d’erreur, très larges, traduisent le caractère improvisé du montage ; les points de charge et de décharge se confondent à leur incertitude près. Deux observations soutiennent l’hypothèse de départ. D’une part, une seule courbe C = A/(d + B) + Cb ajuste l’ensemble des points avec R² = 0,91 : la capacité suit la loi attendue C ∝ 1/d sans qu’il soit nécessaire de distinguer les deux sens du trajet. D’autre part, l’écart entre charge et décharge (≈ 4 % sur A, soit ≈ 0,12 pF en moyenne) reste inférieur à l’incertitude de mesure : aucune hystérésis n’est donc réellement discernable . Approximer le capteur comme non hystérétique est ainsi cohérent avec ces données.

Il faut toutefois rester prudent : cette indiscernabilité tient autant à la faiblesse réelle de l’hystérésis qu’à l’ampleur des incertitudes. Une caractérisation rigoureuse reste nécessaire pour confirmer que l’hystérésis est effectivement négligeable, et non simplement masquée par les incertitudes. C’est l’une des principales ouvertures de ce travail.

## 4 Vers une mesure de la position du point de pression

Au-delà de l’intensité de l’effort, on souhaite aussi détecter la direction de la force appliquée, c’est-à-dire la position du point de pression sur une ligne. Le principe repose sur deux électrodes triangulaires complémentaires, dont les surfaces de recouvrement varient linéairement et de façon opposée avec la position x du point d’appui.

### 4.1 Modèle idéal shield

shield

C1 ∝ x

C2 ∝ (L − x)

point d’appui

x

L (longueur)

(a) Schéma de principe. | (b) Capteur réalisé.

Figure 13. Capteur de position à deux triangles capacitifs complémentaires, avec blindage. (a) Schéma de principe ; (b) photographie du capteur imprimé.

Sur une course totale L, les surfaces de recouvrement donnent :

C1 ∝ x, | C2 ∝ (L − x). | (14)

En supposant la capacité strictement proportionnelle à la surface de recouvrement, la position s’exprime par la formule :

x = L ·

C1
C1 + C2
. | (15)

### 4.2 Limitations pratiques et modèles correctifs

En pratique, la plage du ratio R = C1/(C1 + C2) est bornée, typiquement entre 0,4 et 0,6 au lieu de l’intervalle théorique [0, 1]. Trois effets l’expliquent : les effets de bord (capacité résiduelle à recouvrement nul), le couplage mutuel entre C1 et C2 lorsqu’elles sont proches, et un offset mécanique (le point d’appui ne couvre jamais exactement 0 % ni 100 % de la surface utile).

Modèle avec capacités parasites. On modélise chaque électrode avec une capacité parasite additionnelle Cb (effets de bord) : C

′
1 = C1 + Cb, C

′
2 = C2 + Cb. La position corrigée devient :

x = L ·

C1 − Cb
(C1 − Cb) + (C2 − Cb)
. | (16)

La parasite Cb s’estime à partir des mesures aux positions extrêmes (Rmin, Rmax). Ce modèle explique aussi pourquoi le ratio mesuré reste borné dans un intervalle strictement inclus dans [0, 1] — typiquement R ∈ [0,4 ; 0,6] —, le recouvrement réel ne s’annulant jamais complètement à cause de Cb (démonstration en annexe E).

Modèle empirique affine. Lorsque les effets parasites sont difficiles à modéliser analytique-ment, on utilise une calibration affine x = a R + b, dont les coefficients sont déterminés à partir de deux points connus. Cette approche absorbe tous les effets parasites dans deux constantes, sans modèle physique détaillé. Le problème, c’est que cela absorbe le sens physique, rendant la conception plus compliquée, car cela limite les paramètres sur lesquels on peut jouer.

Modèle | Formule | Paramètres requis
Idéal | x = L · C1 C1 + C2 | L
Avec parasites | x = L · C1 − Cb C1 + C2 − 2Cb | L, Cb
Empirique affine | x = a · C1 C1 + C2
+ b | a, b

Table 1. Modèles de reconstruction de la position, du plus physique au plus empirique.

Détermination de a et b. Les coefficients de la calibration affine x = a R + b (avec R = C1/(C1 + C2)) se déterminent à partir de deux positions connues. On place le point d’appui à deux positions de référence xmin et xmax (par exemple les deux extrémités de la course), et on relève les ratios mesurés correspondants Rmin et Rmax. Les deux conditions xmin = a Rmin + b et xmax = a Rmax + b forment un système linéaire de deux équations à deux inconnues, dont la solution est :
a =

xmax − xmin

Rmax − Rmin

, | b = xmin − a Rmin. | (17)

Afin d’obtenir des valeurs précises, la calibration repose sur une mesure moyennée sur 5 secondes, soit 82 mesures distinctes, ce qui réduit considérablement l’effet du bruit. Une incertitude résiduelle persiste toutefois, qu’elle soit d’origine systématique ou due à la largeur finie de la zone de contact du doigt, qui n’est pas un point unique sur l’axe.

## 5 Conclusion et ouverture

Ce stage avait pour objectif de démontrer la faisabilité de capteurs capacitifs imprimés en 3D pour l’instrumentation d’orthèses, alternative légère et peu coûteuse aux capteurs de force, et d’en caractériser les limites. La démarche a été itérative : concevoir, fabriquer, mesurer, puis identifier les écarts au modèle pour orienter la version suivante.

Le capteur de pression repose sur une mesure différentielle à deux cellules, qui élimine la dépendance à la permittivité et à la surface en ne conservant que le rapport C1/C2. Le premier prototype, à cellules côte à côte, s’est révélé trop sensible à la position du point d’appui ; le second, à électrodes superposées, corrige ce défaut au prix d’un modèle avec ε1 ̸= ε2 ; le troisième introduit un double blindage (masse et actif) pour limiter les couplages avec l’environnement. La reconstruction de l’écartement varie alors dans le bon sens, mais avec des valeurs incohérentes avec le modèle (de l’ordre de 4 mm reconstruits pour 2 mm imposés). La limite principale a été identifiée et interprétée : l’hystérésis du diélectrique en mousse, comprise non comme un défaut de mesure mais comme une propriété de la permittivité dépendante de l’histoire de la déformation.

Le capteur de position, créé à partir de deux électrodes triangulaires complémentaires, fournit la position du point d’appui à partir du seul rapport des surfaces de recouvrement. Là encore, les écarts au modèle idéal — effets de bord, couplage mutuel, offset mécanique — bornent le ratio mesuré, ce qu’un modèle à capacités parasites ou une calibration affine permettent de corriger.

Sur le plan de la faisabilité : les capteurs ont été conçus, fabriqués, et leur principe validé. En revanche, aucune des deux mesures n’atteint encore une précision exploitable telle quelle, et l’hystérésis n’a pas été éliminée mais seulement comprise. Il faut aussi rappeler que la caractérisation du capteur à cellule unique, faute d’imprimantes disponibles pendant la canicule, repose sur des montages bricolés à la main : elle dégage une tendance, non un résultat.

Plusieurs perspectives en découlent directement. (i) L’analyse de la grandeur 1/C2 − 1/C1, plus linéaire et moins hystérétique que C1 ou C2 pris séparément, suggère de remplacer la mousse par un bloc élastomère plein mesuré par une unique cellule, échangeant une part de sensibilité contre une hystérésis fortement réduite. (ii) À l’inverse, un diélectrique essentiellement constitué d’air, la mousse n’assurant que le rappel élastique, supprimerait l’essentiel de l’hystérésis au prix d’une capacité plus faible. (iii) Enfin, une caractérisation rigoureuse — capteurs imprimés en 3D et mesures répétées (n ≥ 3) — reste nécessaire pour trancher si l’hystérésis est réellement négligeable ou simplement masquée par les incertitudes. Dans ces futures versions, le choix de la dureté Shore du matériau, à la frontière entre déformabilité mesurable et réversibilité, apparaît comme le paramètre de conception central. Il pourrait aussi être intéressant d’étudier l’impact du choix de l’algorithme de remplissage sur l’hystérésis et sur la permittivité.

## Remerciements

J’adresse tout particulièrement ma gratitude à Monsieur Maxime Manzano, chercheur au laboratoire Inria et encadrant de ce stage, pour son accompagnement, sa disponibilité et son investissement pour la réussite et le bon déroulement de ce stage. Merci également à tous les membres du site de mécatronique de l’INSA que j’ai pu rencontrer pour leur accueil et leur bienveillance. Je remercie Monsieur Benjamin Audoux, de l’université AMU, pour s’être occupé de la convention de stage. Je remercie également l’université de nous donner l’occasion de réaliser des stages intéressants et enrichissants, et de les intégrer pleinement dans le cursus de la MPCI.

## Références

[1] Manzano, M., Gallois, M., Guégan, S., Le Breton, R., Devigne, L., et Babel, M. (juin 2025). « Enhancing the Usability of Upper-Limb Assistive Robots with a Variable Admittance Control-ler. » Dans : Actes du Colloque "Jeunes Chercheuses, Jeunes Chercheurs" IFRATH 2025, vol. 2025, p. 14–19. ISBN : 978-2-9571218-4-7. HAL : https://hal.science/hal-05356901
[2] Manzano, M., Guégan, S., Le Breton, R., Devigne, L., et Babel, M. (oct. 2024). « Force-Triggered Control Design for User Intent-Driven Assistive Upper-Limb Robots. » Dans : 2024 IEEE/RSJ International Conference on Intelligent Robots and Systems (IROS), p. 135–140. DOI : 10.1109/IROS58592.2024.10801685. (https://doi.org/10.1109/IROS58592.2024.10801685) HAL : https://hal.science/hal-04774539v1
[3] Aguilar-Segovia, J. E. (2026). Additive Manufacturing of Deformable Sensing Devices for Human–Machine Interaction and their Customization in the Layered Fabrication Space. Thèse de doctorat, INSA Rennes. HAL : https://theses.hal.science/tel-05587063v1
[4] Aguilar-Segovia, J. E., Manzano, M., Guégan, S., Le Breton, R., Farhi-Rivasseau, A., Lefebvre, S., et Babel, M. (2024). « Multi-material torque sensor embedding one-shot 3D-printed deformable capacitive structures. » IEEE Sensors Letters, 8(9), p. 1–4. HAL : https://hal.science/hal-04699911v1 (https://hal.science/hal-04699911v1)

## A Capacité équivalente en série

On démontre la formule des condensateurs en série à partir de C = εS/d.

### 1. Conservation de la charge. Deux condensateurs C1 et C12 en série. Les armatures

intérieures forment un conducteur isolé : aucune charge ne peut y entrer ou sortir, donc chaque condensateur porte la même charge Q. On a C1 = ε1S/d1 et C12 = ε2S/∆d.

### 2. Relation de Chasles sur les potentiels. En notant VA, VB, VC, VD les potentiels des

quatre armatures (A, D extérieures ; B, C intérieures reliées, donc VB = VC) :

VA − VD = (VA − VB) + (VC − VD) = ∆V1 + ∆V2.

### 3. Expression des tensions. Avec ∆Vi = Qdi/(εiS) :

∆Vtotal =

Q
S

d1
ε1

+

∆d
ε2

### 4. Identification. Par définition Céq = Q/∆Vtotal, donc en simplifiant par Q ̸= 0 :

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
C’est la formule utilisée en (6) pour modéliser la cellule inférieure du capteur de pression à électrodes superposées.

## B Expression de C2 en fonction de d

On démontre ici la forme C2(d) = Sε1/(α ∆d + d) utilisée au critère de conception (section 3.1.2).

Point de départ. On repart de la relation série (6) :

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
Mise au même dénominateur. En factorisant par 1/ε1 :

1
C2

=

1
S ε1
d +

ε1
ε2

∆d

Introduction de α. Avec α = ε1/ε2 (défini en (8)) :

1
C2

=

d + α ∆d
S ε1

Inversion. En passant à l’inverse, on obtient la forme annoncée :

C2(d) = S ε1 α ∆d + d

La dérivée par rapport à d s’en déduit :

∂C2
∂d = −

S ε1
(α ∆d + d)

2

,

| ∂C2 ∂d (d0)

=

S ε1
(α ∆d + d0)

2

## C Méthode des moindres carrés

Définition C.1 (Méthode des moindres carrés). Étant donné un modèle f(d ; θ) et des mesures (di

, Ci)i=1...N , la méthode des moindres carrés cherche le jeu de paramètres θ

⋆
minimisant la fonction de coût — la somme des carrés des écarts entre modèle et mesure :

J(θ) = X

N

i=1

Ci − f(di

; θ)

2
, θ⋆ = arg min θ
J(θ).

Élever les écarts au carré pénalise fortement les grandes erreurs et rend le coût différentiable ; le minimum annule le gradient ∇θJ = 0. En pratique, on confie cette minimisation à un algorithme numérique (scipy.optimize.least_squares()) de Python, provenant du module NumPy/SciPy.

## D Coefficient de détermination

Définition D.1 (Coefficient de détermination). Pour un modèle Cˆ i = f(di) ajusté sur les
mesures (di

, Ci), le coefficient de détermination

R

2 = 1 −

P
i

(Ci − Cˆ
i)

2
P
i

(Ci − C¯)
2

= 1 −

SSres

SStot

compare l’erreur résiduelle du modèle à la dispersion totale des données. Une valeur proche de 1 signifie que le modèle correspond bien à la réalité.

## E Bornes du ratio du capteur de position

On justifie ici que le ratio R = C1/(C1 +C2) du capteur de position reste borné dans un intervalle strictement inclus dans [0, 1] (section 4.2).

Notons R = C1/(C1 + C2) le ratio brut. Avec la capacité parasite, le ratio mesuré devient

R =

C1 + Cb
C1 + C2 + 2Cb

Aux positions extrêmes, le recouvrement réel s’annule (C1 → 0 ou C2 → 0), mais la parasite Cb > 0 subsiste :

Rmin =

Cb
C2 + 2Cb

(en C1 = 0), Rmax =

C1 + Cb
C1 + 2Cb

(en C2 = 0).

On a donc 0 < Rmin ≤ R ≤ Rmax < 1 : le ratio n’atteint jamais 0 ni 1, et x = L R reste borné dans [L Rmin, L Rmax] ⊊ [0, L]. C’est exactement la borne observée expérimentalement (R ∈ [0,4 ; 0,6]) : plus C1 ou C2 est grand devant Ctot, plus l’intervalle se contracte autour de 1/2.

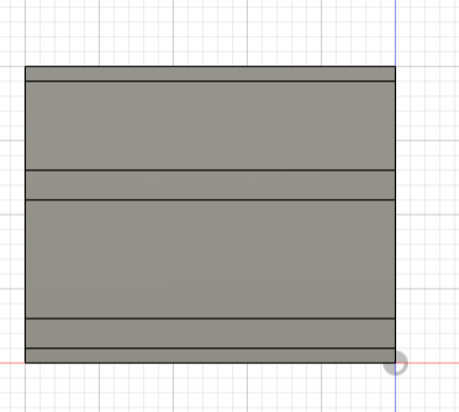
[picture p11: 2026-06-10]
figures/prototypes/V1.2_empile.png

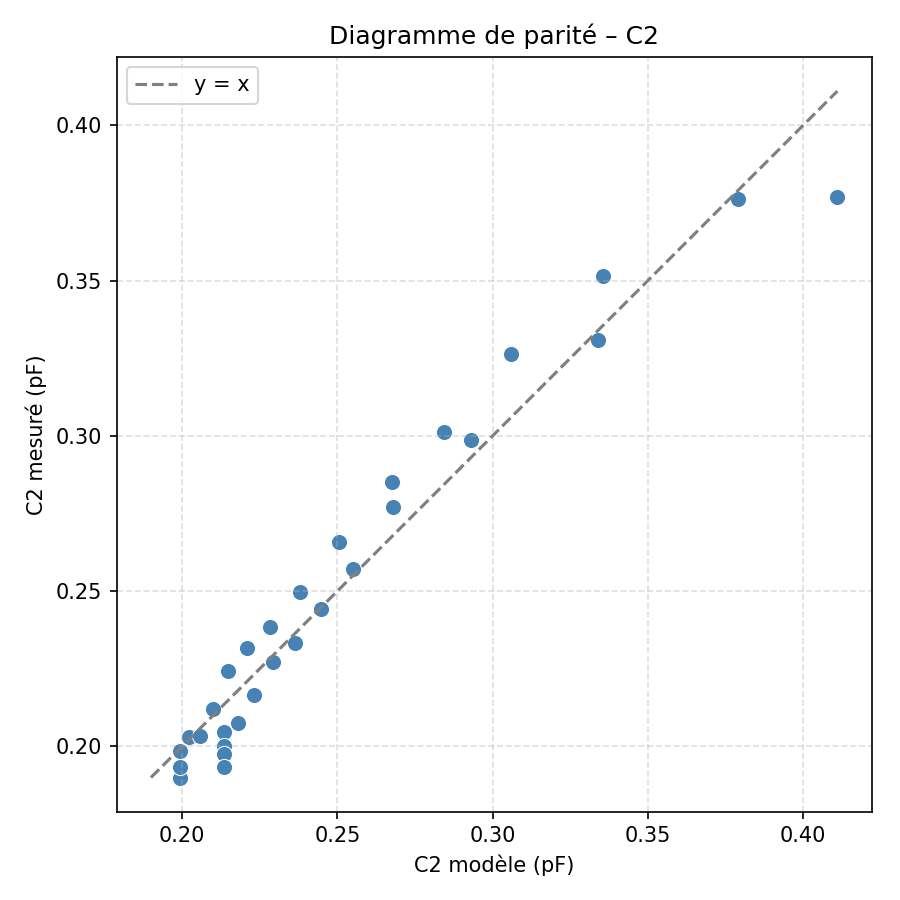
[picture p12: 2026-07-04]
figures/analysis/C2_parity.png

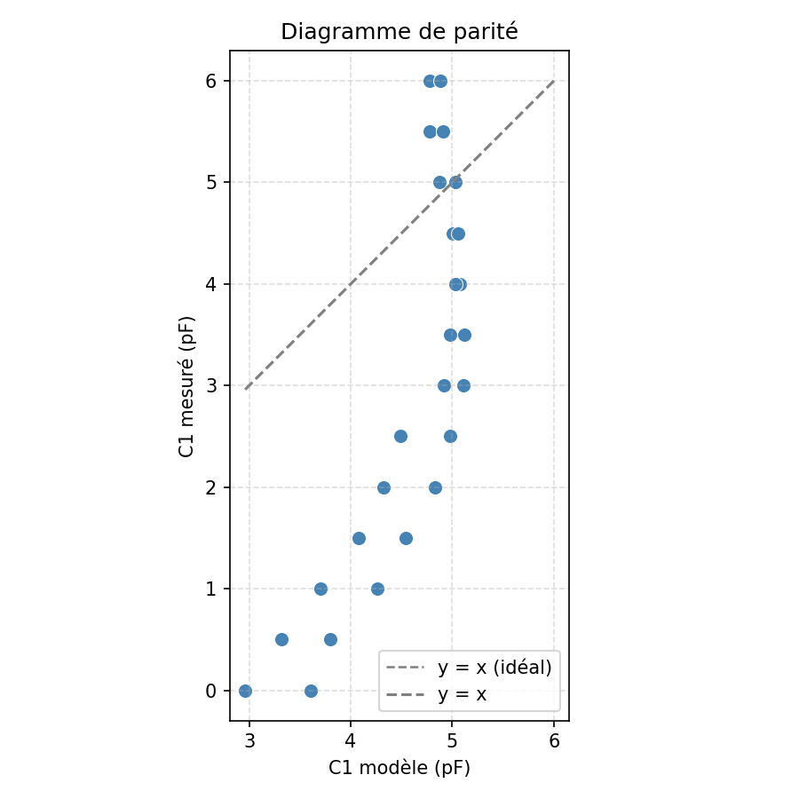
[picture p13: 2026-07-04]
figures/analysis/C1_parity_hysteresis.png

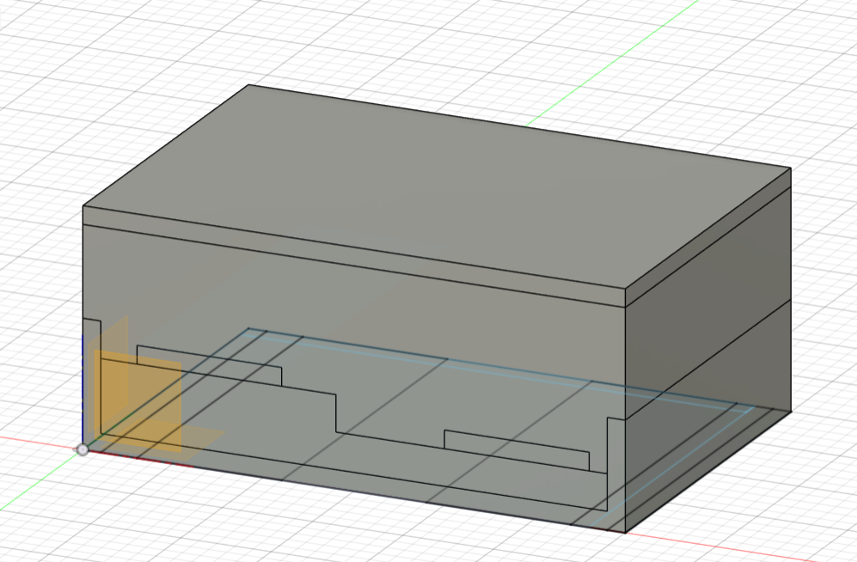
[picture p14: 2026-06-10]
figures/prototypes/Perspective_cavalière.png

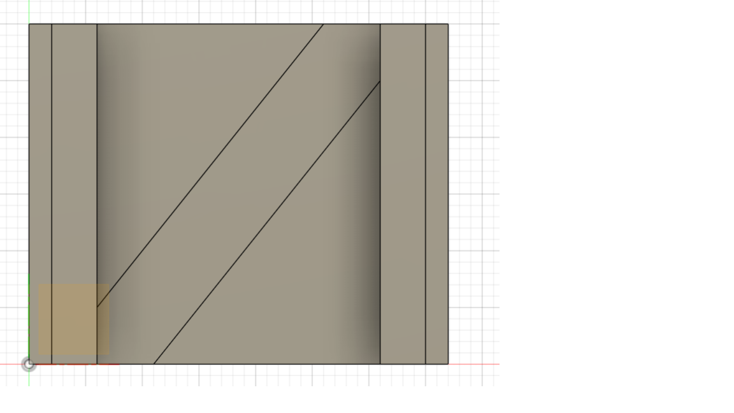
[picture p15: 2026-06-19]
figures/prototypes/Position_V4.png

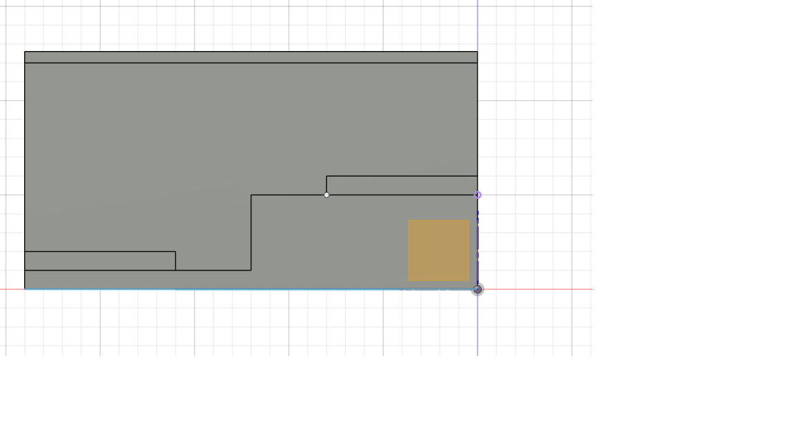
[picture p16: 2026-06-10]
figures/prototypes/Vue de face.png

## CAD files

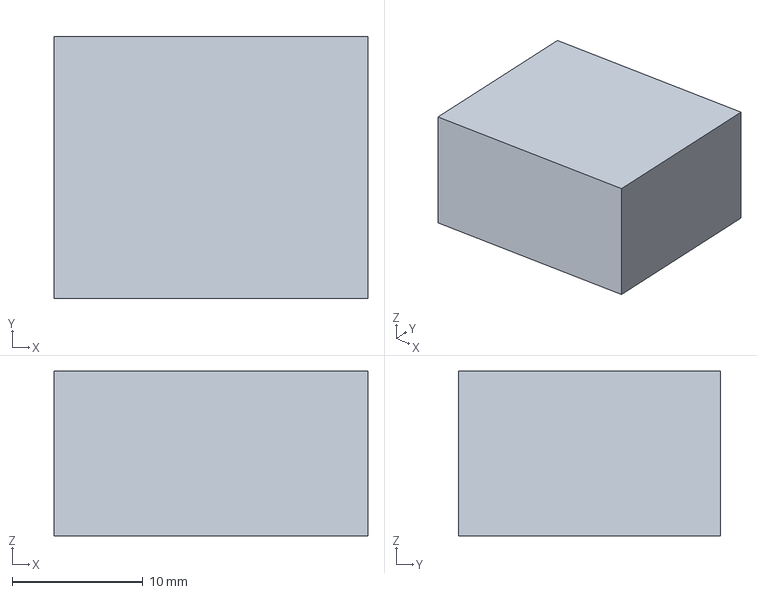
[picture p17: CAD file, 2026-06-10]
cad/v1_cellules_cote_a_cote/V1.1/V1 pour Prusa.3mf
24.0 x 20.0 x 12.6 mm

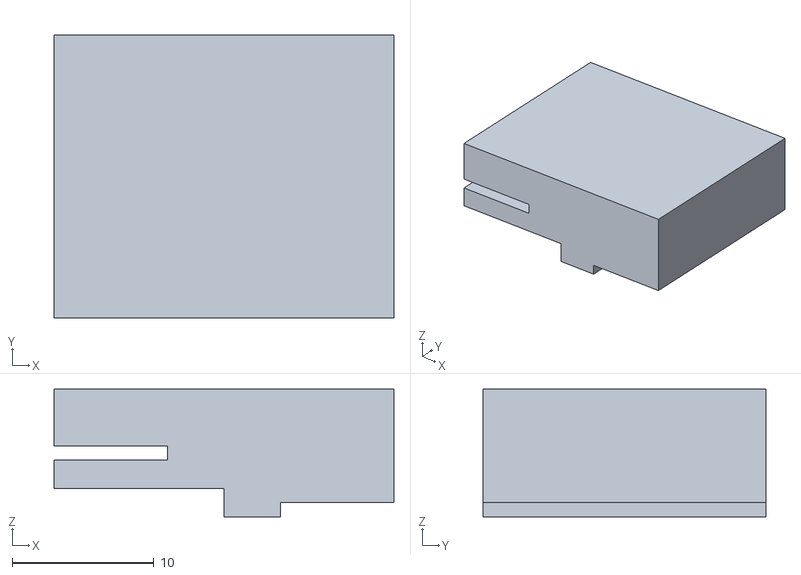
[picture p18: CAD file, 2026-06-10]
cad/v1_cellules_cote_a_cote/V1.1/V1.1 en variant Delta d/Mousse.stl
24.0 x 20.0 x 9.00

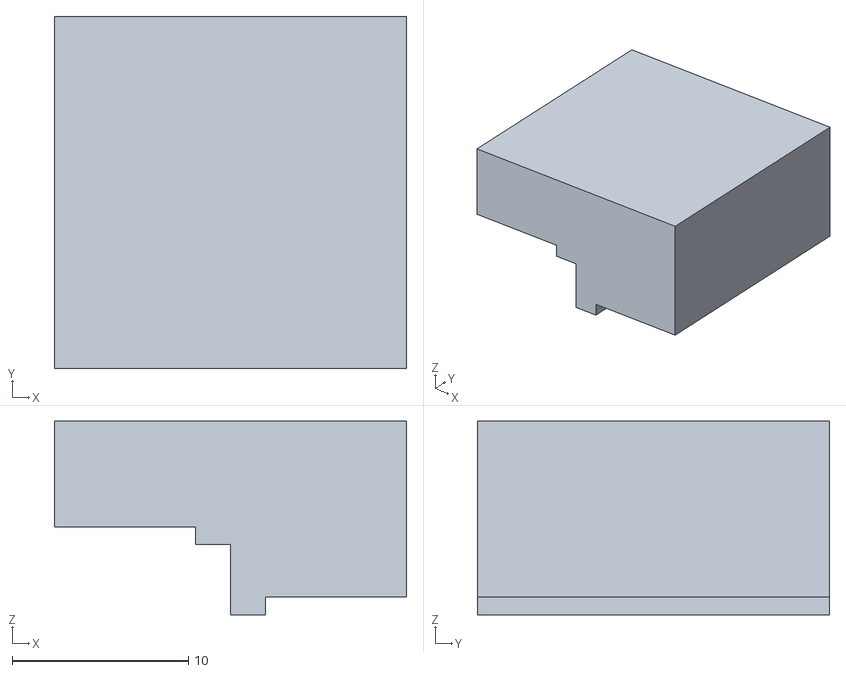
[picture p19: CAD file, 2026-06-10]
cad/v1_cellules_cote_a_cote/V1.1/v1.1 en variant Delta x/Mousse.stl
20.0 x 20.0 x 11.0

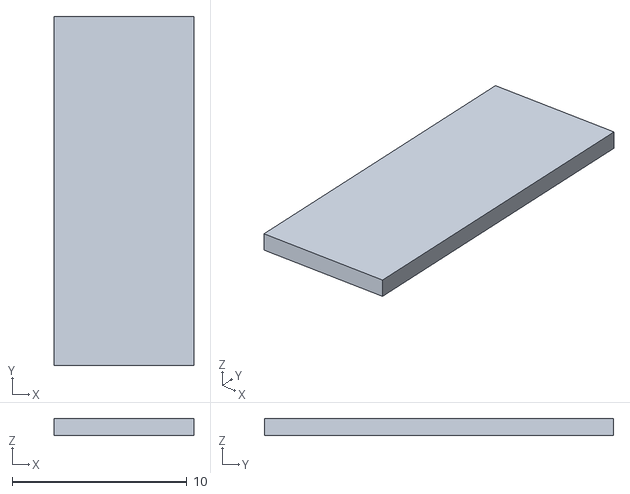
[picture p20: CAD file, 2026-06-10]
cad/v1_cellules_cote_a_cote/V1.1/V1.1 stl classique/Conducteur_d.stl
8.00 x 20.0 x 1.00

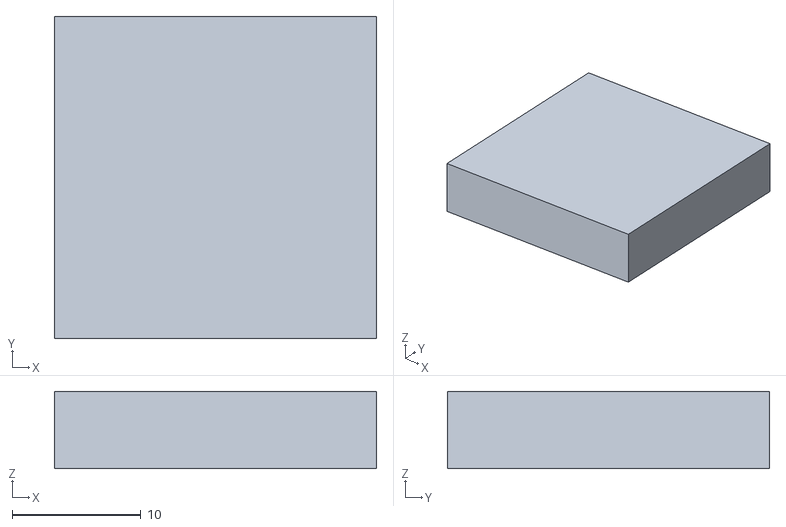
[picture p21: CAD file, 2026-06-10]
cad/v1_cellules_cote_a_cote/V1.2 empilé/Mousse.stl
25.0 x 25.0 x 6.00

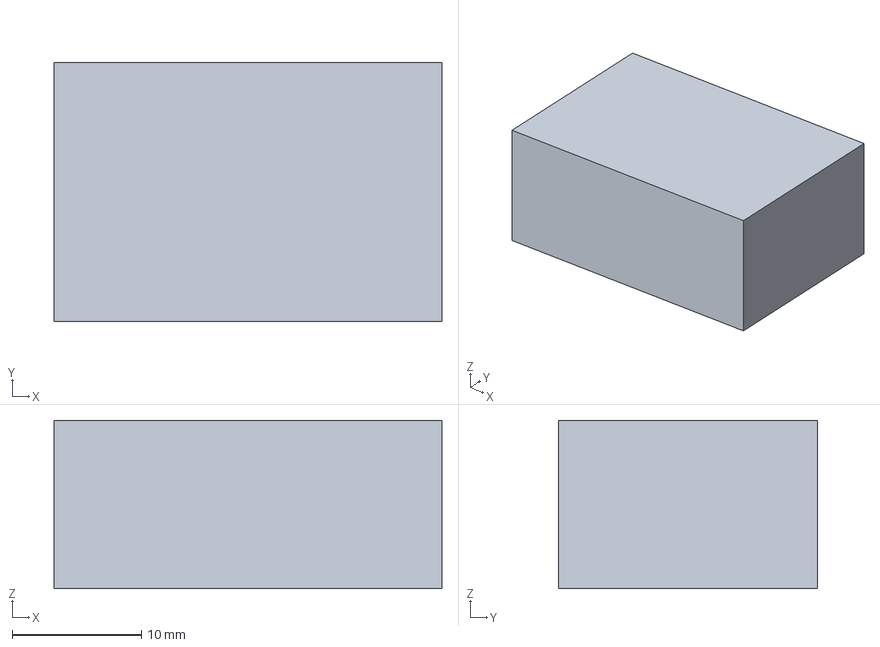
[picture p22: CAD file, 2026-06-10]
cad/v2_blindage/V2.1 STL/V2 pour Prusa.3mf
30.0 x 20.0 x 13.0 mm

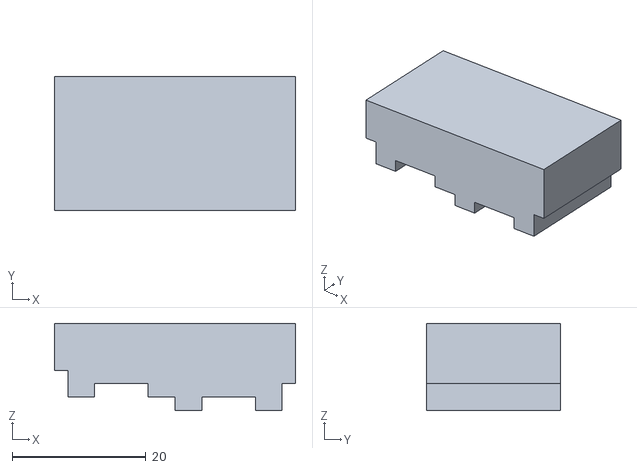
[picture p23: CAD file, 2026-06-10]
cad/v2_blindage/V2.3/Mousse (1).stl
36.0 x 20.0 x 13.0

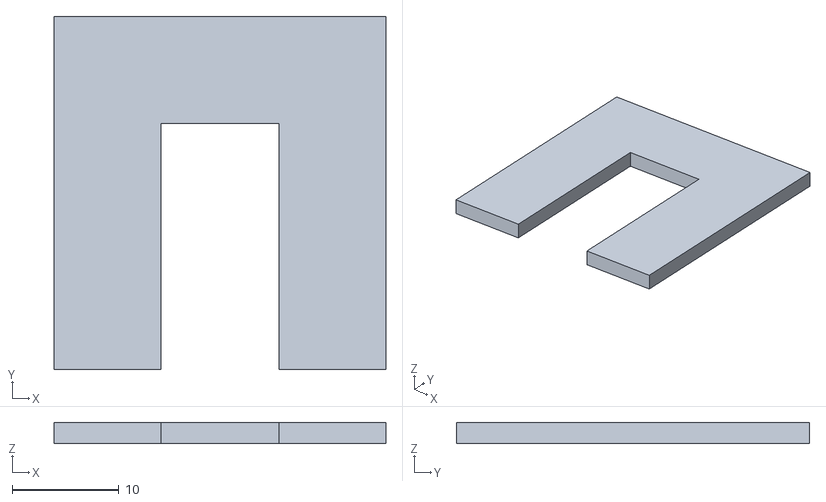
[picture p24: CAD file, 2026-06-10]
cad/v3_superpose_blinde/V3.2/plateau_non_conducteur.stl
31.0 x 33.0 x 2.00

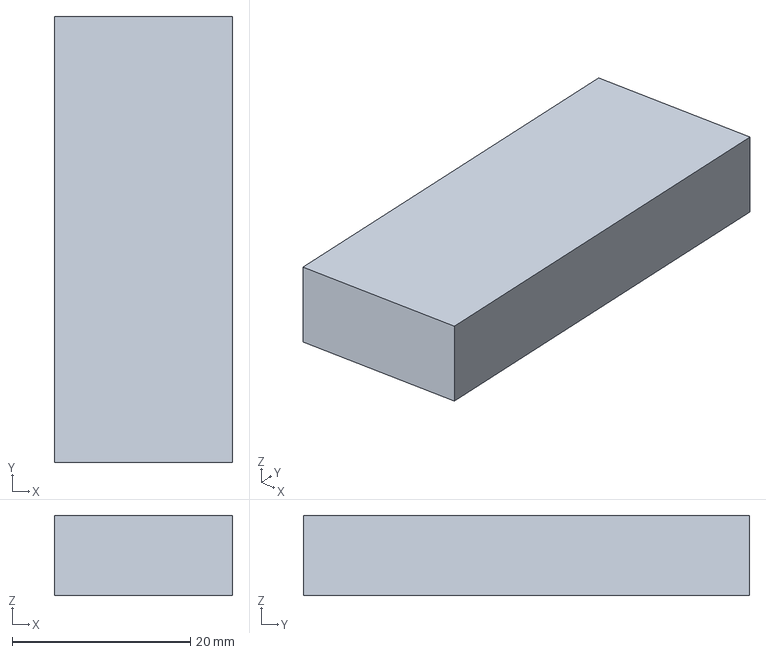
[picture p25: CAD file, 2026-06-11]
cad/v3_superpose_blinde/v3.3.3mf
20.0 x 50.0 x 9.00 mm

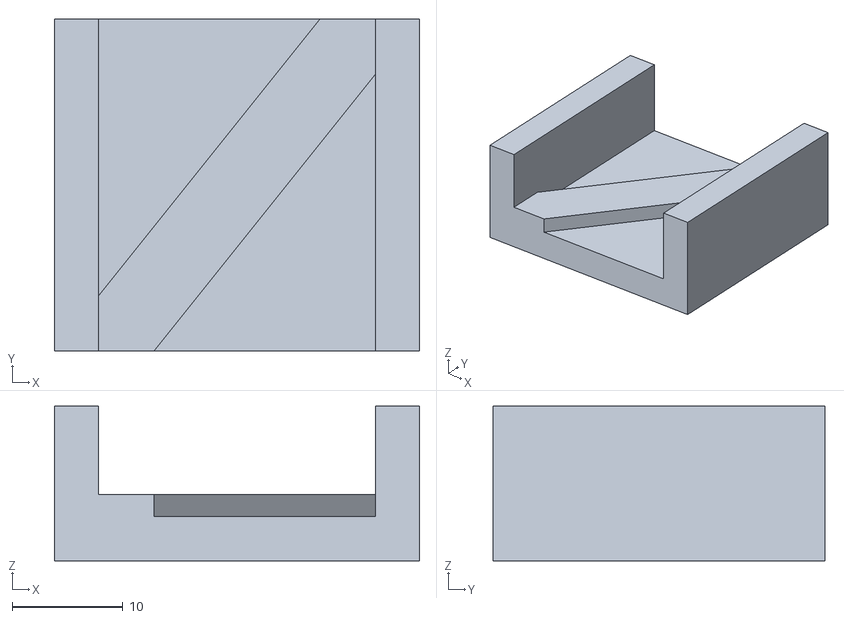
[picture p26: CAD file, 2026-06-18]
cad/v4_position/V4.3/Support.stl
33.0 x 30.0 x 14.0

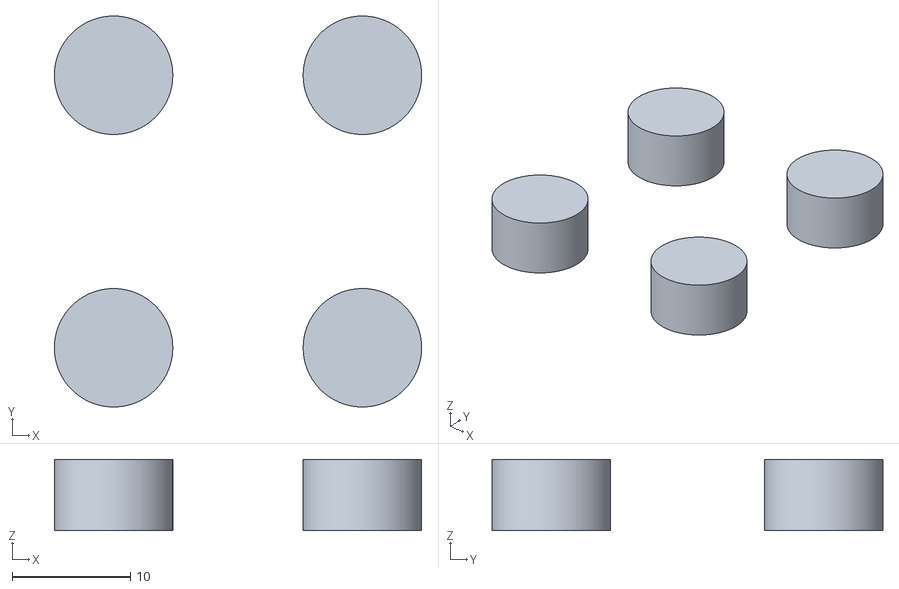
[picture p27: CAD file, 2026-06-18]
cad/v5_test_pilier/Mousse_haute.stl
31.0 x 33.0 x 6.00

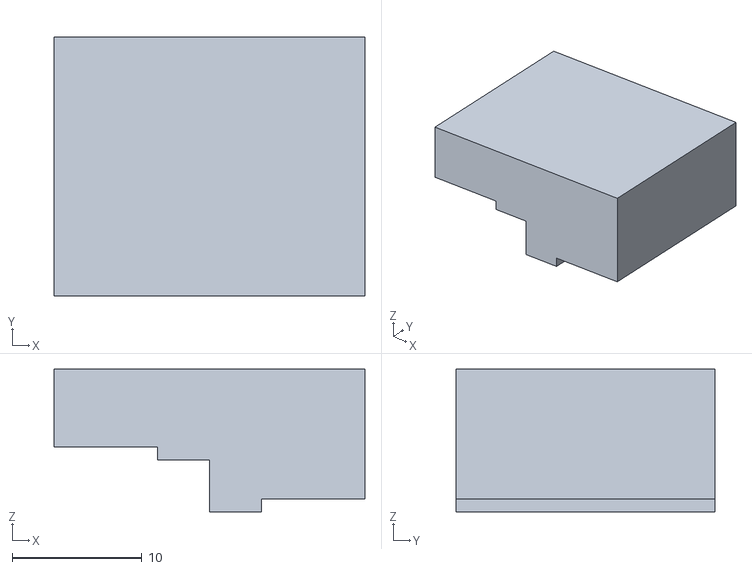
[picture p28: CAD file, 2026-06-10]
cad/v1_cellules_cote_a_cote/V1.1/V1.1 stl classique/Mousse.stl
24.0 x 20.0 x 11.0

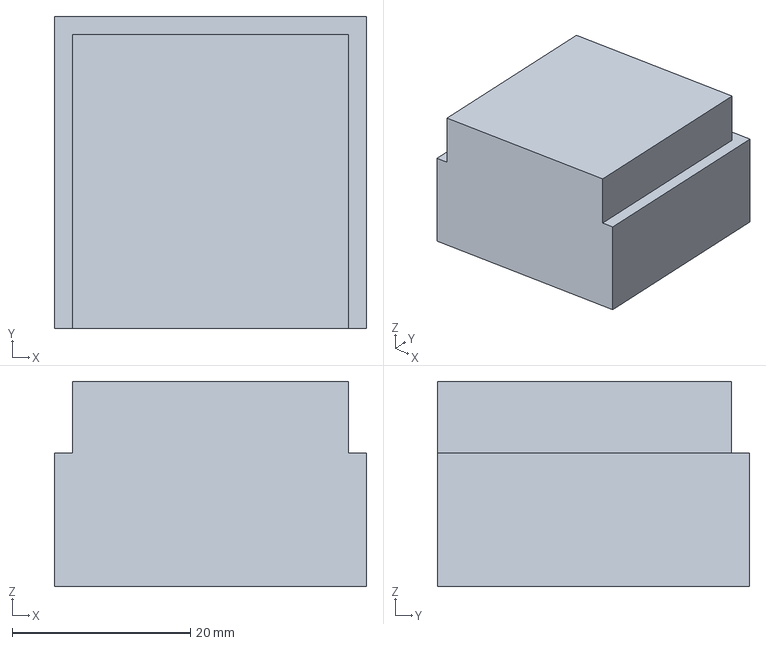
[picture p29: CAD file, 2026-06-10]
cad/v1_cellules_cote_a_cote/V1.2 empilé/Capteur_empile.3mf
35.0 x 35.0 x 23.0 mm

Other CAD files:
cad/v4_position/v4.3mf
cad/v1_cellules_cote_a_cote/V1.1/v1.1 en variant Delta x/Conducteur_gauche.stl
cad/v2_blindage/V2.1 STL/Conducteur_g.stl
cad/v1_cellules_cote_a_cote/V1.1/V1.1 en variant Delta d/Conducteur_gauche.stl
cad/v1_cellules_cote_a_cote/V1.1/V1.1 en variant Delta d/Plateau.stl
cad/v1_cellules_cote_a_cote/V1.1/V1.1 en variant Delta d/Support.stl
cad/v1_cellules_cote_a_cote/V1.1/V1.1 stl classique/Conducteur_gauche.stl
cad/v1_cellules_cote_a_cote/V1.1/V1.1 stl classique/Plateau.stl
cad/v1_cellules_cote_a_cote/V1.1/V1.1 stl classique/Support.stl
cad/v1_cellules_cote_a_cote/V1.1/modele_fusion_V1.1.f3d
cad/v1_cellules_cote_a_cote/V1.1/v1.1 en variant Delta x/Conducteur_d.stl
cad/v1_cellules_cote_a_cote/V1.1/v1.1 en variant Delta x/Plateau.stl
cad/v1_cellules_cote_a_cote/V1.1/v1.1 en variant Delta x/Support.stl
cad/v1_cellules_cote_a_cote/V1.2 empilé/Conducteur_bas.stl
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

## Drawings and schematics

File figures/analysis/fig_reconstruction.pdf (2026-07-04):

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

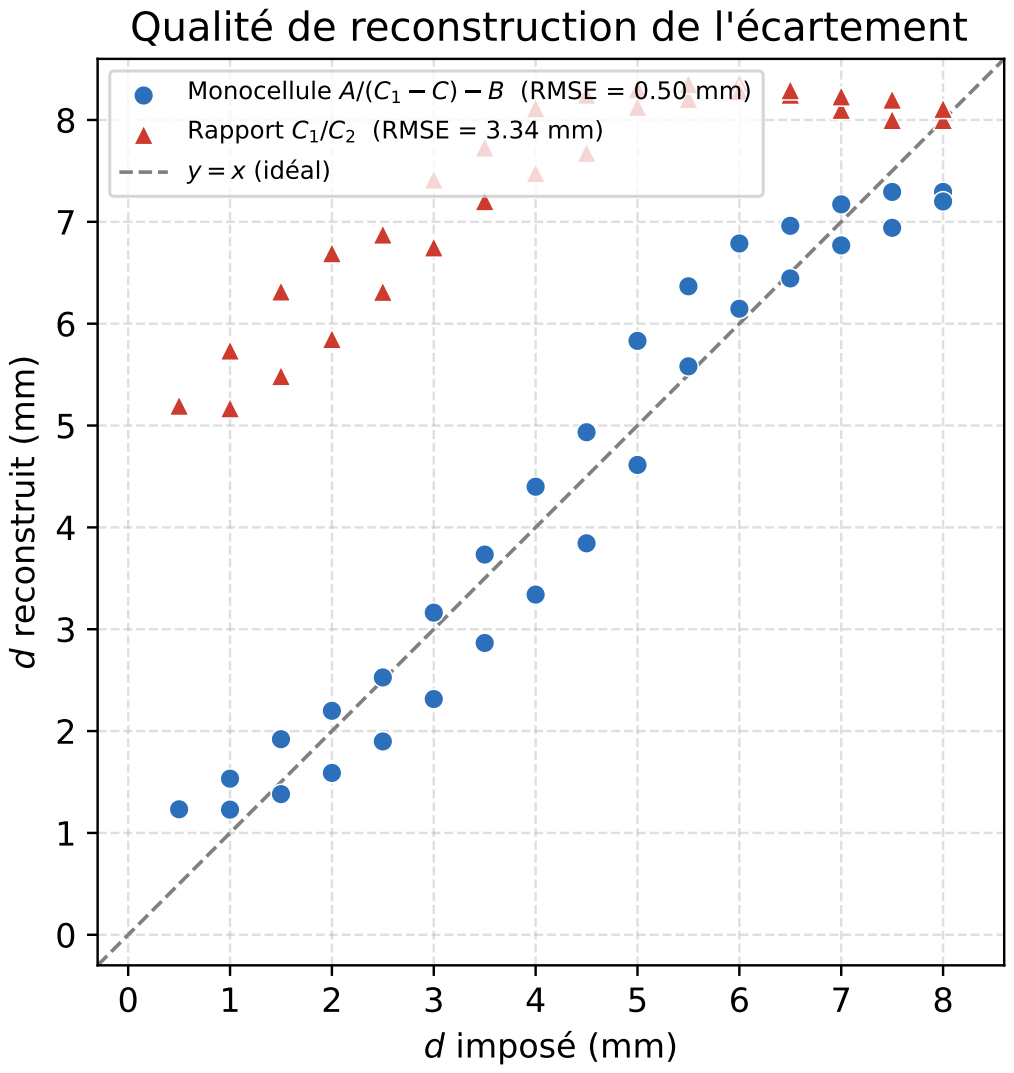
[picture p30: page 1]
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

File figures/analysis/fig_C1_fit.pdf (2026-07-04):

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

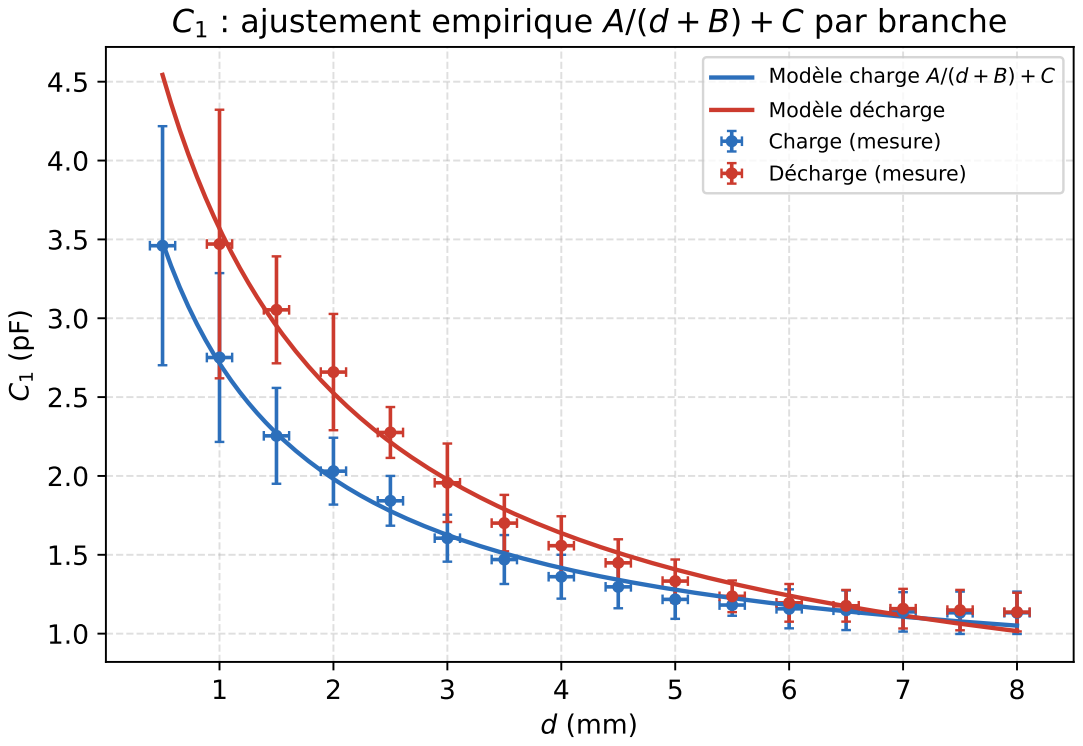
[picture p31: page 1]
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

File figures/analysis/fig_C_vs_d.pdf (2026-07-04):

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

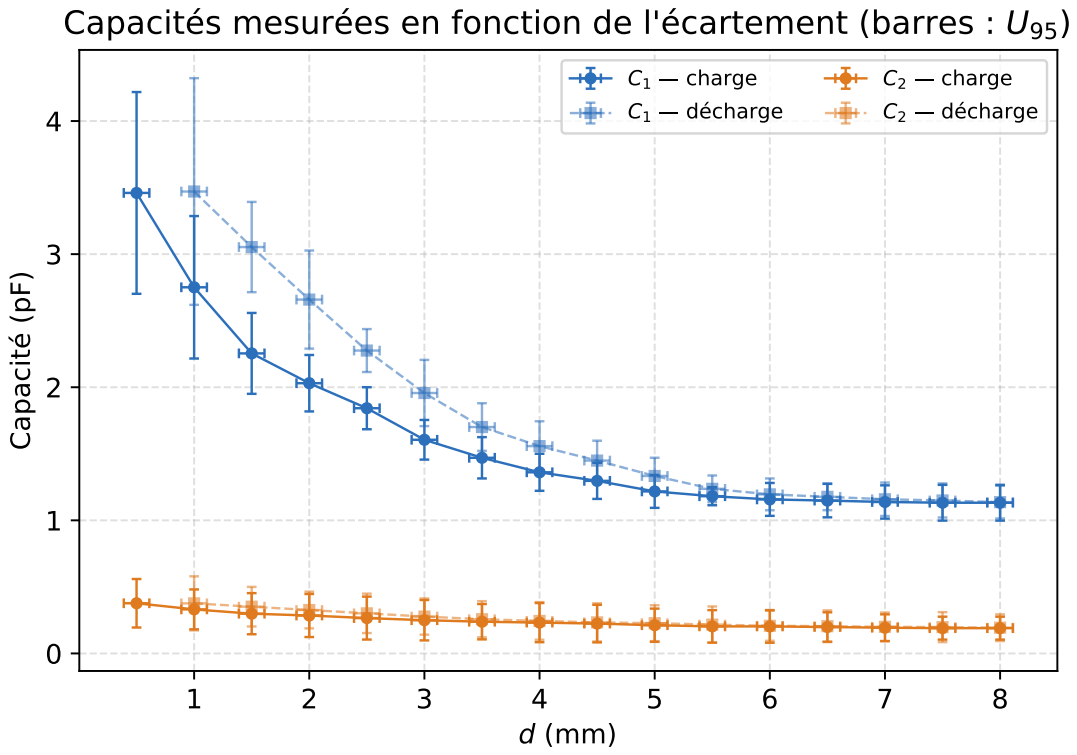
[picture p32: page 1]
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

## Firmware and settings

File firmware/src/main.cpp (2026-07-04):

#include <Arduino.h>
#include <M5Stack.h>
#include <Wire.h>
#include <Protocentral_FDC1004.h>
#include <cmath>


#define UPPER_BOUND  0X4000
#define LOWER_BOUND  (-1 * UPPER_BOUND)
#define MEASURMENT 0

int capdac = 0;
int32_t capacitance = 0, capacitance2 = 0;
FDC1004 FDC;

// --- Constantes de calibration ---
const float deltad = 8.0f;   // écart fixe entre les deux capteurs (mm)
const float d0     = 6.0f;  // distance de référence mesurée mécaniquement (mm)
float eS = 0;


// --- Variables de calibration (mesurées à l'origine) ---
float C10 = 0.0f;
float C20 = 0.0f;
float alpha = 0.0f;  // epsilon1/epsilon2, constant
bool calibrated = false;
float f0 = 0;

// --- Lecture d'un canal FDC1004 ---
float readCapacitance(uint8_t channel) {
  FDC.configureMeasurementSingle(MEASURMENT, channel, capdac);
  FDC.triggerSingleMeasurement(MEASURMENT, FDC1004_100HZ);
  delay(15);

  uint16_t value[2];
  if (!FDC.readMeasurement(MEASURMENT, value)) {
    int16_t msb = (int16_t)value[0];
    int32_t cap = ((int32_t)457) * ((int32_t)msb);
    cap /= 1000;
    cap += ((int32_t)3028) * ((int32_t)capdac);

    if (msb > UPPER_BOUND && capdac < FDC1004_CAPDAC_MAX) capdac++;
    else if (msb < LOWER_BOUND && capdac > 0)             capdac--;

    return (float)cap / 1000.0f;  // en picofarads
  }
  return NAN;
}

void setup() {
  M5.begin(true, false, true, true);
  Wire.begin();
  Serial.begin(115200);

  // --- Calibration à l'origine ---
  // On attend 500ms pour que le capteur se stabilise
  delay(500);

  // Moyenne sur 10 lectures pour plus de robustesse
  float sum1 = 0, sum2 = 0;
  const int N = 10;
  for (int i = 0; i < N; i++) {
    sum1 += readCapacitance(0);
    sum2 += readCapacitance(1);
    delay(20);
  }
  C10 = sum1 / N;
  C20 = sum2 / N;
  f0 = C10/ C20;

  // rapport_eps = (epsilon1/epsilon2), admis constant
  alpha = ((C10 / C20) -1 )* (d0 / (deltad));

  Serial.print(">C10 (pF):"); Serial.println(C10, 4);
  Serial.print(">C20 (pF):"); Serial.println(C20, 4);
  Serial.print(">rapport_eps:"); Serial.println(alpha, 6);

  calibrated = true;
  eS = C20 * deltad;
}

void loop() {
  if (!calibrated) return;

  float C1 = readCapacitance(0);
  float C2 = readCapacitance(1);
  float f = C1/C2;
  if (isnan(C1) || isnan(C2)) return;

  Serial.print(">C1 (pF):"); Serial.println(C1, 4);
  Serial.print(">C2 (pF):"); Serial.println(C2, 4);
  Serial.print(">C1/C2 (pF):"); Serial.println(C1/ C2, 4);

 Serial.print(">ration des c :"); Serial.println(C1/C2, 6);
 Serial.print(">ration des  eps:"); Serial.println(alpha, 6);
 float d = eS / C2;
 Serial.print(">distance  :"); Serial.println((d), 6);

}

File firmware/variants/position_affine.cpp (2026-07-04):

#include <Arduino.h>
#include <M5Stack.h>
#include <Wire.h>
#include <Protocentral_FDC1004.h>
#include <cmath>

#define UPPER_BOUND  0X4000
#define LOWER_BOUND  (-1 * UPPER_BOUND)
#define MEASURMENT 0

int capdac = 0;
FDC1004 FDC;

const float L = 30.0f;

const float x_min = 0.0f;   // gauche
const float x_max = L;      // droite

const unsigned long CALIB_MS = 5000;  // duree de moyennage par point (5 s)

float R_min = 0.0f;   // mesure BtnA (basse, droite)  -> x = L
float R_max = 0.0f;   // mesure BtnB (haute, gauche)  -> x = 0

bool calibrated = false;

float Cp = 0.0f;

// Droite : x = slope * R + intercept (passe exactement par les 2 extremites)
float slope = 0.0f;
float intercept = 0.0f;


float readCapacitance(uint8_t channel) {
  FDC.configureMeasurementSingle(MEASURMENT, channel, capdac);
  FDC.triggerSingleMeasurement(MEASURMENT, FDC1004_100HZ);
  delay(15);

  uint16_t value[2];
  if (!FDC.readMeasurement(MEASURMENT, value)) {
    int16_t msb = (int16_t)value[0];
    int32_t cap = ((int32_t)457) * ((int32_t)msb);
    cap /= 1000;
    cap += ((int32_t)3028) * ((int32_t)capdac);

    if (msb > UPPER_BOUND && capdac < FDC1004_CAPDAC_MAX) capdac++;
    else if (msb < LOWER_BOUND && capdac > 0)             capdac--;

    return (float)cap / 1000.0f;  // picofarads
  }
  return NAN;
}

float calcul_ratio(float C1, float C2) {
  float c1c = C1 - Cp;
  float c2c = C2 - Cp;
  if ((c1c + c2c) == 0) return NAN;
  return c1c / (c1c + c2c);
}

// Moyenne C1 et C2 sur CALIB_MS millisecondes, puis renvoie R moyen.
// Affiche un compte a rebours sur le LCD. Retourne NAN si echec.
float calibPoint(const char* nom) {
  double sumC1 = 0.0, sumC2 = 0.0;
  long   n = 0;
  unsigned long t0 = millis();

  while (millis() - t0 < CALIB_MS) {
    float C1 = readCapacitance(0);
    float C2 = readCapacitance(1);
    if (!isnan(C1) && !isnan(C2)) {
      sumC1 += C1;
      sumC2 += C2;
      n++;
    }
    float reste = (CALIB_MS - (millis() - t0)) / 1000.0f;
    M5.Lcd.setCursor(0, 80);
    M5.Lcd.printf("Mesure... %.1f s   ", reste);
    delay(20);
  }

  if (n == 0) {
    Serial.println("Erreur lecture — recommencer");
    return NAN;
  }

  float C1m = (float)(sumC1 / n);
  float C2m = (float)(sumC2 / n);
  float R   = C1m / (C1m + C2m);

  Serial.print(">"); Serial.print(nom); Serial.print("_R: ");  Serial.println(R, 6);
  Serial.print(">"); Serial.print(nom); Serial.print("_C1: "); Serial.println(C1m, 4);
  Serial.print(">"); Serial.print(nom); Serial.print("_C2: "); Serial.println(C2m, 4);
  Serial.print(">"); Serial.print(nom); Serial.print("_N: ");  Serial.println(n);
  return R;
}

// Droite passant par les 2 extremites (R_min,x_max) et (R_max,x_min).
bool fitLinear(float R1, float x1, float R2, float x2) {
  if (fabs(R2 - R1) < 1e-9f) {
    Serial.println("ERREUR: R identiques, regression impossible");
    return false;
  }
  slope = (x2 - x1) / (R2 - R1);
  intercept = x1 - slope * R1;
  return true;
}

float ratioToPosition(float R) {
  return slope * R + intercept;
}

// Attend l'appui du bouton voulu puis lance le moyennage 5 s.
float waitAndCalib(int btn, const char* nom) {
  while (true) {
    M5.update();
    bool pressed = (btn == 0) ? M5.BtnA.wasPressed() : M5.BtnB.wasPressed();
    if (pressed) {
      float R = calibPoint(nom);
      if (!isnan(R)) return R;
    }
    delay(30);
  }
}

void setup() {
  M5.begin(true, false, true, true);
  Wire.begin();
  Serial.begin(115200);

  M5.Lcd.setTextSize(2);

  // --- Point BASSE (droite) : BtnA -> x = L ---
  M5.Lcd.clear();
  M5.Lcd.setCursor(0, 0);
  M5.Lcd.println("A -> basse (droite)");
  Serial.println("Curseur BASSE (droite) puis appuyer sur A");
  R_min = waitAndCalib(0, "low");

  // --- Point HAUTE (gauche) : BtnB -> x = 0 ---
  M5.Lcd.clear();
  M5.Lcd.setCursor(0, 0);
  M5.Lcd.println("Basse OK");
  M5.Lcd.println("B -> haute (gauche)");
  Serial.println("Curseur HAUTE (gauche) puis appuyer sur B");
  R_max = waitAndCalib(1, "high");
  Cp = 0.0f;

  // --- Verifications ---
  if (fabs(R_max - R_min) < 1e-4f) {
    Serial.println("ERREUR: R_low == R_high, calibration impossible");
    while (true) delay(1000);
  }

  // Droite passant exactement par :
  //  R_min -> x = L (droite) ,  R_max -> x = 0 (gauche)
  if (!fitLinear(R_min, x_max, R_max, x_min)) {
    while (true) delay(1000);
  }

  Serial.print(">slope: ");     Serial.println(slope, 6);
  Serial.print(">intercept: "); Serial.println(intercept, 6);
  Serial.print(">Cp (pF): ");   Serial.println(Cp, 4);

  M5.Lcd.clear();
  M5.Lcd.setCursor(0, 0);
  M5.Lcd.println("Calibration OK");
  delay(1000);

  calibrated = true;
}

void loop() {
  if (!calibrated) return;

  float C1 = readCapacitance(0);
  float C2 = readCapacitance(1);
  if (isnan(C1) || isnan(C2)) return;

  float R = calcul_ratio(C1, C2);
  if (isnan(R)) return;

  float position = ratioToPosition(R);
  position = constrain(position, x_min, x_max);

  Serial.print(">C1 (pF):"); Serial.println(C1, 4);
  Serial.print(">Ratio R:"); Serial.println(R, 6);
  Serial.print(">Position (mm):"); Serial.println(position, 2);
  M5.Lcd.clear();
  M5.Lcd.setCursor(0, 0);
  M5.Lcd.setTextSize(2);
  M5.Lcd.print("R = "); M5.Lcd.println(R, 4);
  M5.Lcd.print("x = "); M5.Lcd.print(position, 1); M5.Lcd.println(" mm");

  delay(50);
}

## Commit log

2026-07-04 Restructure: clean layout, bilingual READMEs, tested analysis scripts
    [4.3.3mf, Book1.csv, Book1.xlsx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]
2026-07-09 Remove docstring from analyse_capacites_condensateur.py
    Removed the initial docstring that describes the analysis of capacitor capacities.
2026-07-09 Remove docstring from analyse_capacitive.py
    Removed the initial docstring explaining the analysis of a differential capacitive sensor.

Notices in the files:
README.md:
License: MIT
